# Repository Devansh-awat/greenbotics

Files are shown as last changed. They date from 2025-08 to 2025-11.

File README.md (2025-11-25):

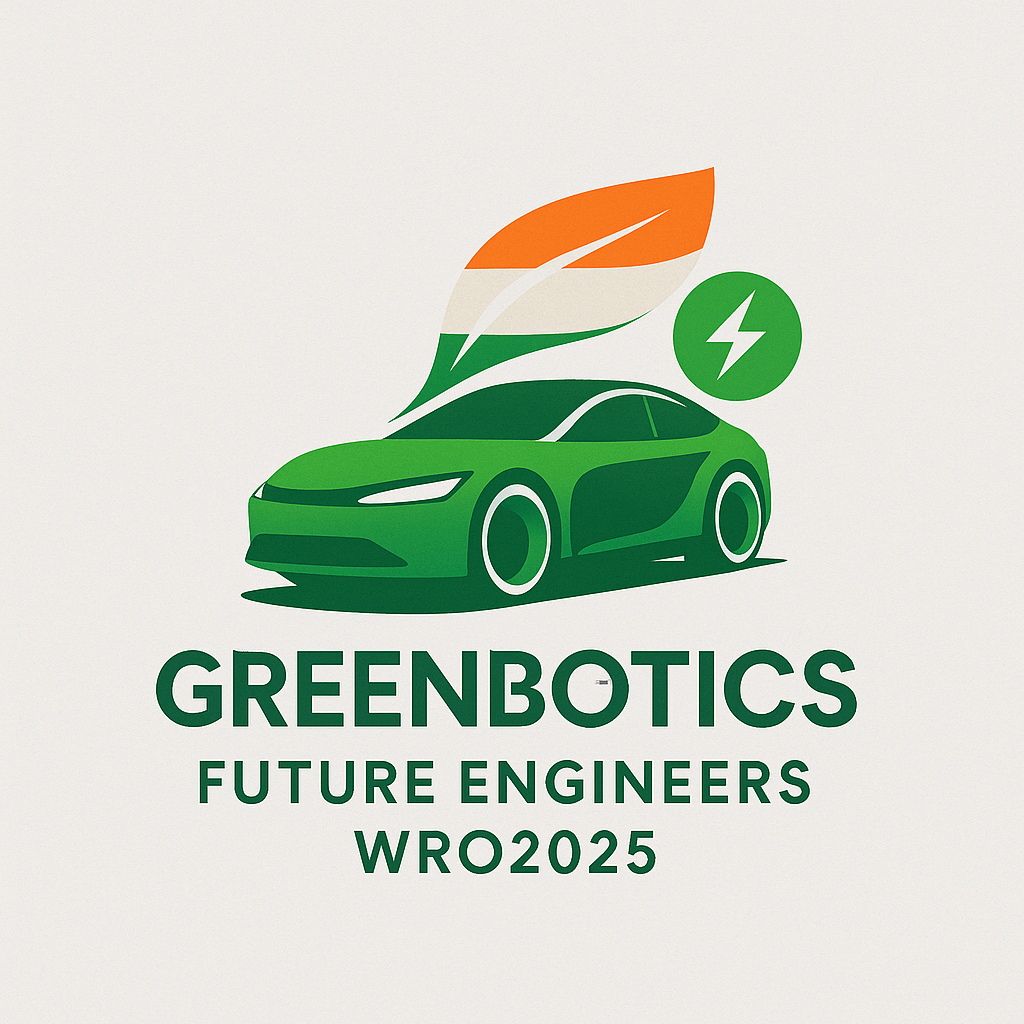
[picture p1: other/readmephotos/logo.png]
|  |
| :----------------------------------------------------------: |

| GithubQR | YoutubeQR |
| :--- | ---: |
| Scan QR to open Github repo | Scan QR to open YouTube video |

<div style="font-family: Baskerville; font-size: 28px; text-align: center; font-style: italic;">
    This Incredible Repository
</div>

Welcome to the Greenbotics 2025 repository! This repository contains everything we've worked on over the past ten months, including all our code and resources. You can also use this repository as a complete guide to understand and reconstruct the robot from the ground up.

## Table of Contents

- [The Team](#the-team)
- [The Challenge](#the-challenge)
  - [Our Vision](#our-vision)
  - [Skills We Learned](#skills-we-learned)
- [Photos of our Robot](#photos-of-our-robot)
- [Robot Performance Video](#robot-performance-video)
- [Mobility Management](#mobility-management)
  - [Powertrain](#powertrain)
  - [Steering System](#steering-system)
  - [Chassis](#chassis)
  - [Code for mobility components](#code-for-mobility-components)
- [Power and Sense Management](#power-and-sense-management)
  - [LiPo battery](#lipo-battery)
  - [Raspberry Pi](#raspberry-pi)
  - [Voltage Converter](#voltage-converter)
  - [Printed Circuit Board (PCB)](#printed-circuit-board-pcb)
  - [Camera](#camera)
  - [IMU](#imu)
  - [Distance Sensor](#distance-sensor)
  - [Multiplexer](#multiplexer)
  - [Code for sensors](#code-for-sensors)
- [Obstacle Management](#obstacle-management)
  - [Open Challenge Navigation Algorithm](#open-challenge-navigation-algorithm)
    - [Potential improvements in Open Navigation Algorithm](#potential-improvements-in-open-navigation-algorithm)
  - [Obstacle Challenge Navigation Algorithm](#obstacle-challenge-navigation-algorithm)
    - [Potential improvements in Obstacle Navigation Algorithm](#potential-improvements-in-obstacle-navigation-algorithm)
- [Engineering Factors](#engineering-factors)
  - [Design evolution](#design-evolution)
  - [From Nationals to Internationals!](#from-nationals-to-internationals)
- [Robot construction guide](#robot-construction-guide)
  - [1: Print the 3D parts](#1-print-the-3d-parts)
  - [2: Assemble the steering and drive train](#2-assemble-the-steering-and-drive-train)
  - [3: Attach the 3D mounts](#3-attach-the-3d-mounts)
  - [4: Fabricate the PCB](#4-fabricate-the-pcb)
  - [5: Soldering the electronics and gradual safe startup](#5-soldering-the-electronics-and-gradual-safe-startup)
  - [6: Download the code](#6-download-the-code)
  - [7: Robot stability](#7-robot-stability)
- [Major challenges faced](#major-challenges-faced)
- [How we used Github](#how-we-used-github)
- [Bill of Materials](#bill-of-materials)

# The Team

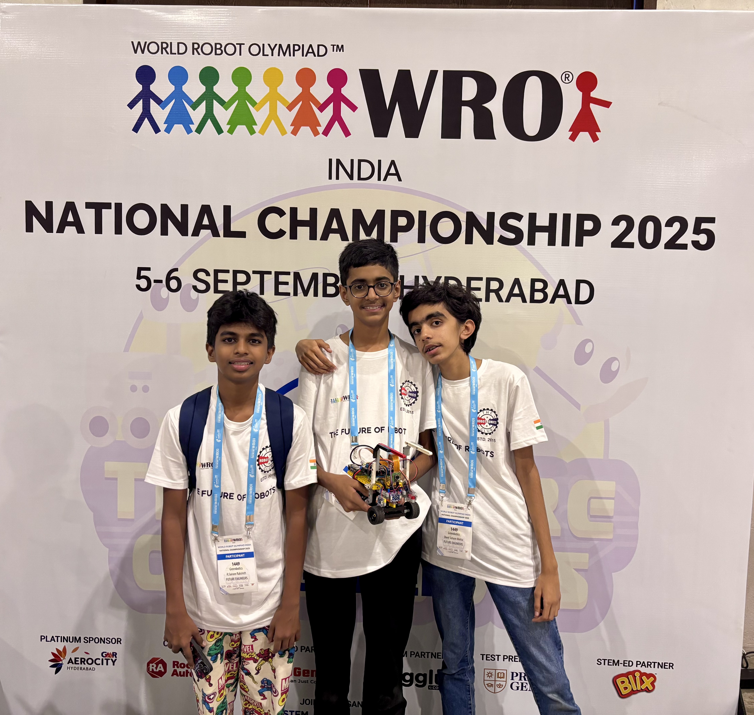
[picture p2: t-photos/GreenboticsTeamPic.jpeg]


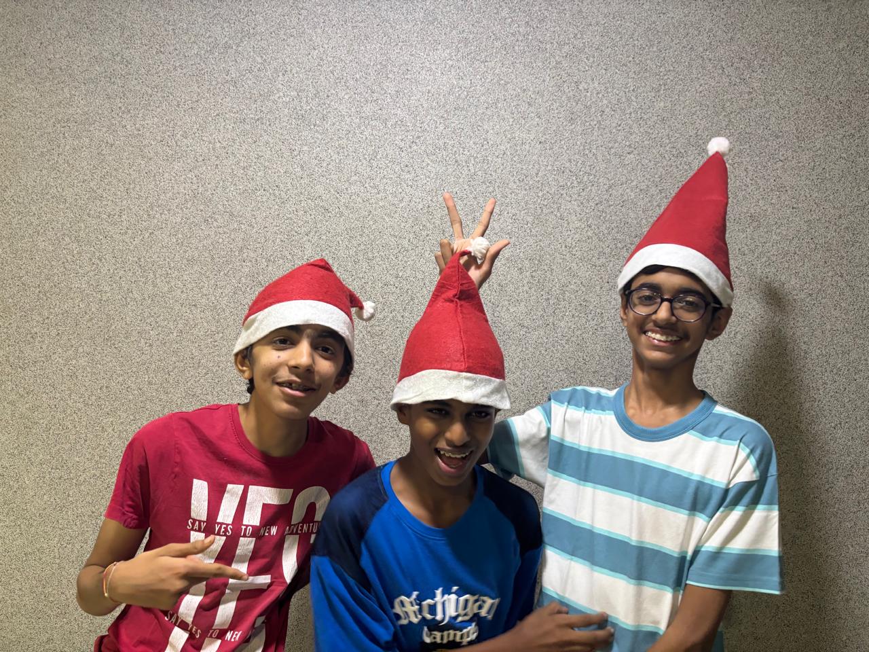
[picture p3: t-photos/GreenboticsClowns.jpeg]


<p style="text-align:center;">Yes. We did know the camera was on!</p>

---

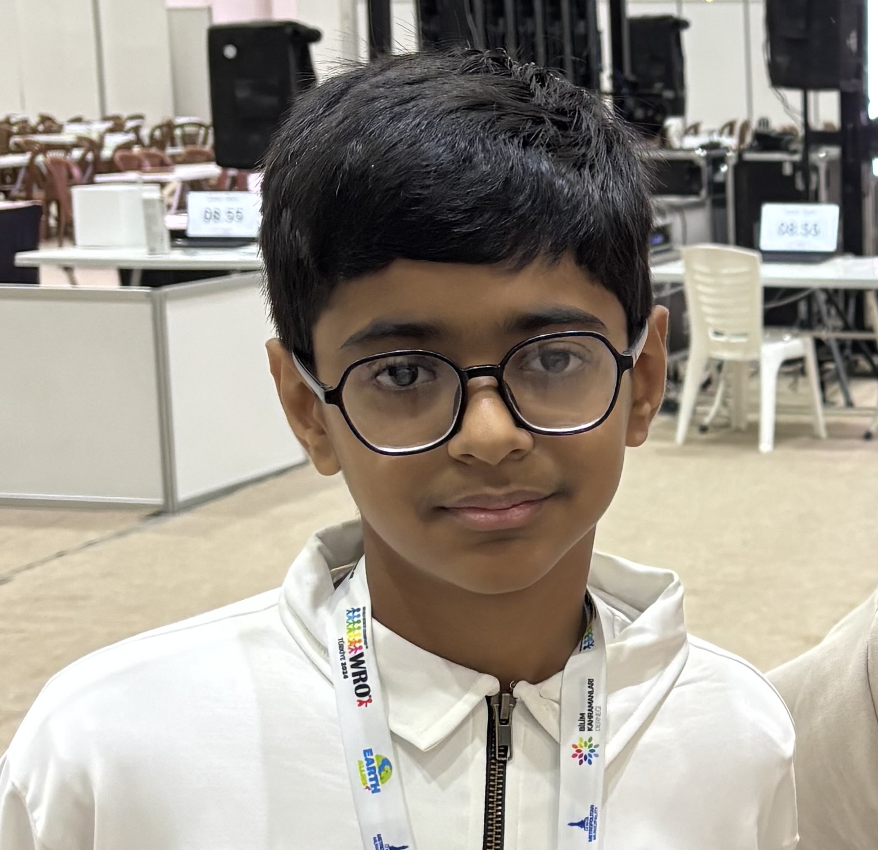
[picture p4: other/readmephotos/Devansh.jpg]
|  | Devansh<br/>Hi! I’m Devansh doing my second WRO season. Last year I represented India in the RoboMission category coming #25 in Internationals. This year I wanted a new challenge and learn new things. My hobbies are coding and robotics. |
| --- | --- |
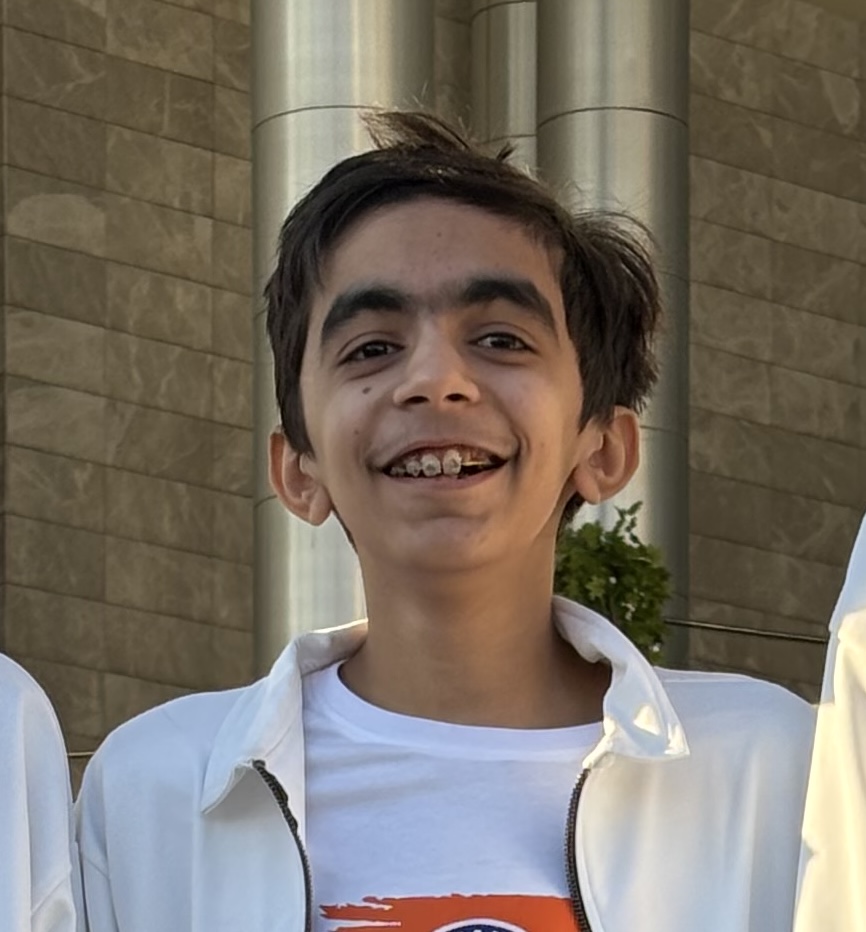
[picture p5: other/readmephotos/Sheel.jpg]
|  | **Sheel**<br/>**Hi! I'm Sheel. I'm 15, and doing my second WRO season. Last year, our team made it to the International Finals in Robomission Junior. Additionally, I'm learning competitive debate. I also have a dog, and both of us are obsessed with Monkeys.** |
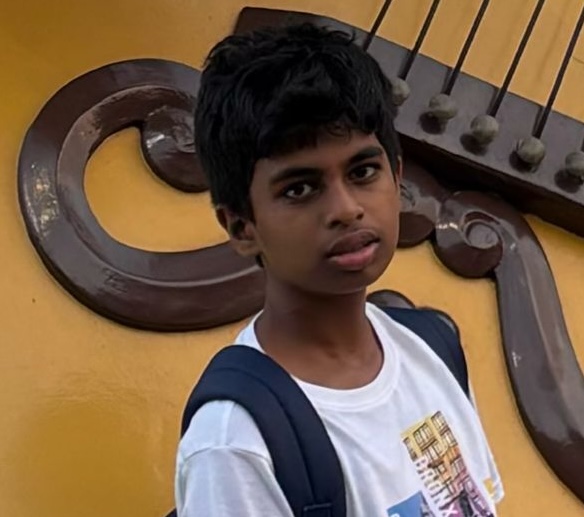
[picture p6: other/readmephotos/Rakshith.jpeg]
|  | **Rakshith**<br/>**I'm Rakshith, a 9th grader passionate about robotics and aspiring to study engineering in Germany. I love building drones, experimenting with sensors. I also have 3 dogs, and two of them live with my grandparents in Hyderabad.** |
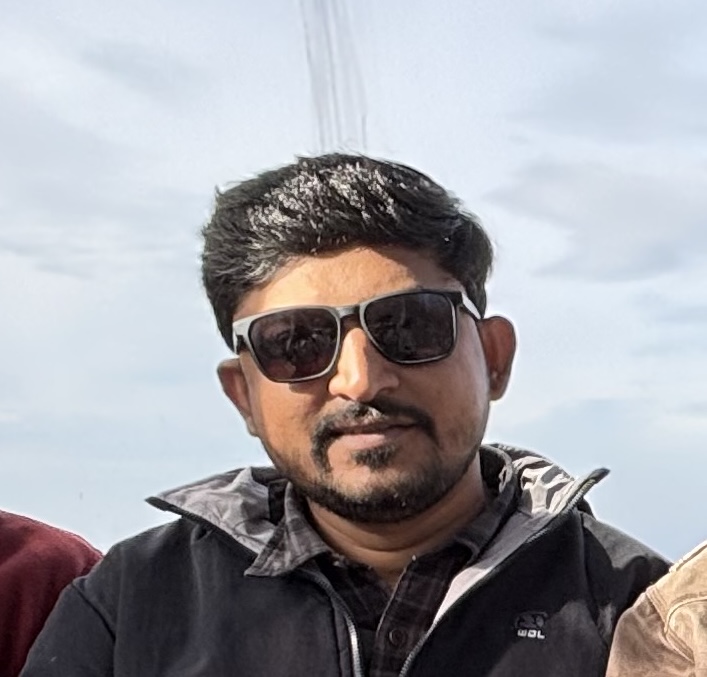
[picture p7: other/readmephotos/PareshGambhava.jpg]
|  | **Paresh Gambhava**<br/>**Mr. Paresh Gambhava is our chief coach from The Robotronics Club Ahmedabad. He is a robotics enthusiast, and electrical engineer by profession. He has vast experience training students for Robotics competition and projects.** |

# The Challenge

The [Future Engineer Challenge](https://wro-association.org/wp-content/uploads/WRO-2025-Future-Engineers-Self-Driving-Cars-General-Rules.pdf "View the season rulebook") for the 2025 WRO Season involves building an autonomous vehicle that can complete two challenges. The first challenge is the Open Challenge. This challenge involves the robot completing three full laps on the field. The field consists of outer boundary walls, and 4 inner walls that are randomly placed to form a closed rectangle.

The second challenge is the Obstacle Challenge. In the Obstacle Challenge red or green cuboids called Traffic Signs are placed along the course. The robot must complete three laps around the track while making sure to pass the red traffic signs from the left, and the green traffic signs from the right. The Obstacle Challenge also has a dedicated Parking Space. The robot must start and end in the parking space to attain full points. The walls placement is fixed for the Obstacle Challenge.

## Our Vision

With a deep interest in robotics and programming, the WRO Future engineers challenge was a great opportunity for us to work and build a robot together. We had been seeing other teams in our institute work on this problem last year, and it was greatly motivating for us to see them work. Having represented India in last years WRO RoboMission, we were excited to participate in new category and learn new things.

## Skills We Learned

**Technical Skills:**

- 3D printing and design
- PCB design and creation
- Raspberry Pi programming
- Computer vision and camera programming
- Hardware integration

**Soft Skills:**

- Teamwork
- Problem-solving
- Not go crazy when the robot doesn’t behave as expected !!!

# Photos of our Robot

We designed our robot with Raspberry Pi 5 as the main brain of the car. Raspberry Pi 5 had pre-integrations with the camera allowing us to use faster smarter image procesing algorithms which is critical in this robots design.
Having spent a lot of time working on LEGO-based hardware in the 2024 season, we chose to use many LEGO parts for our Robot's Hardware.  However the robot also uses a Raspberry Pi, Raspberry Pi camera, and other off the shelf electronic components.

| Top view | Bottom view |
| :---: | :---: |
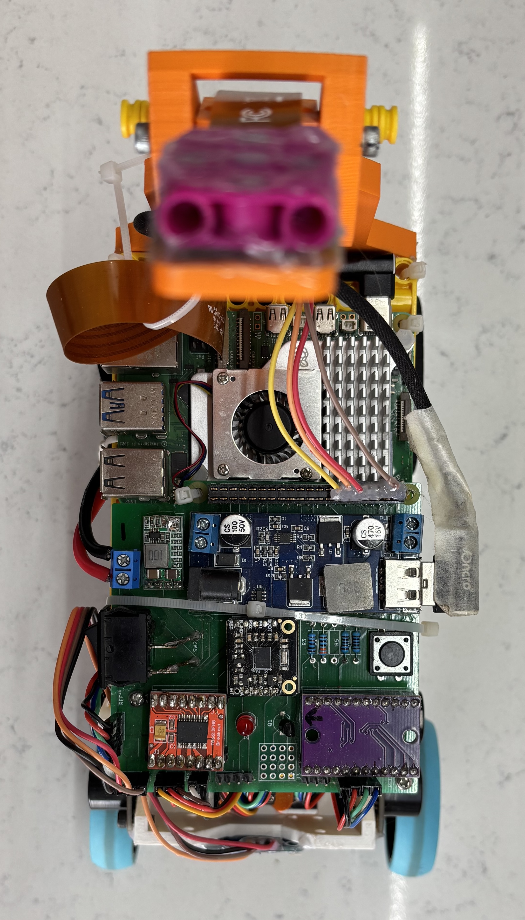
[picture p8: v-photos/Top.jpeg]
Top
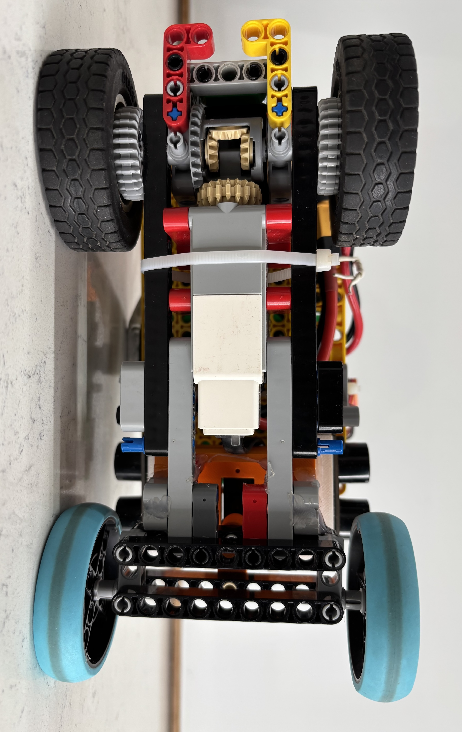
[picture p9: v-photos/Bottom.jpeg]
Bottom
|  |  |

| Front view | Rear view |
| :---: | :---: |
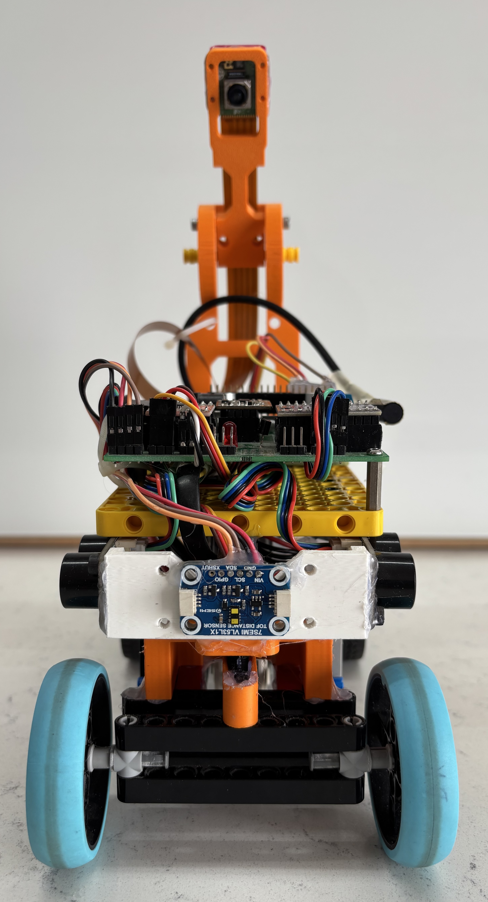
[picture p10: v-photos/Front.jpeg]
Front
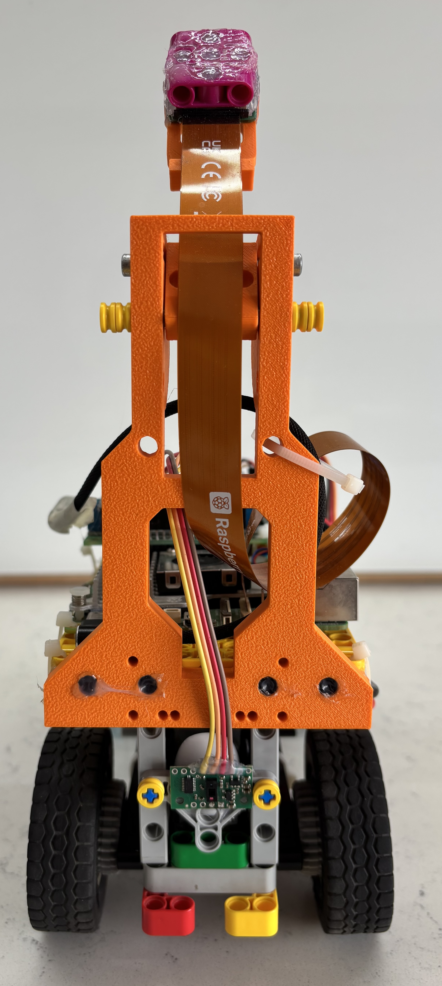
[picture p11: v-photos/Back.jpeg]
Back
|  |  |

| Left view | Right view |
| :---: | --- |
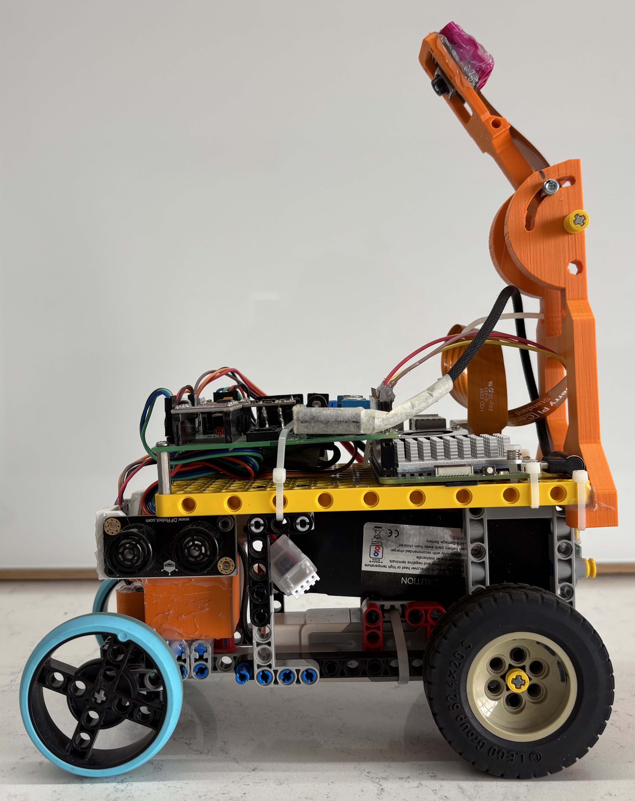
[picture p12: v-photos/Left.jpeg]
Left
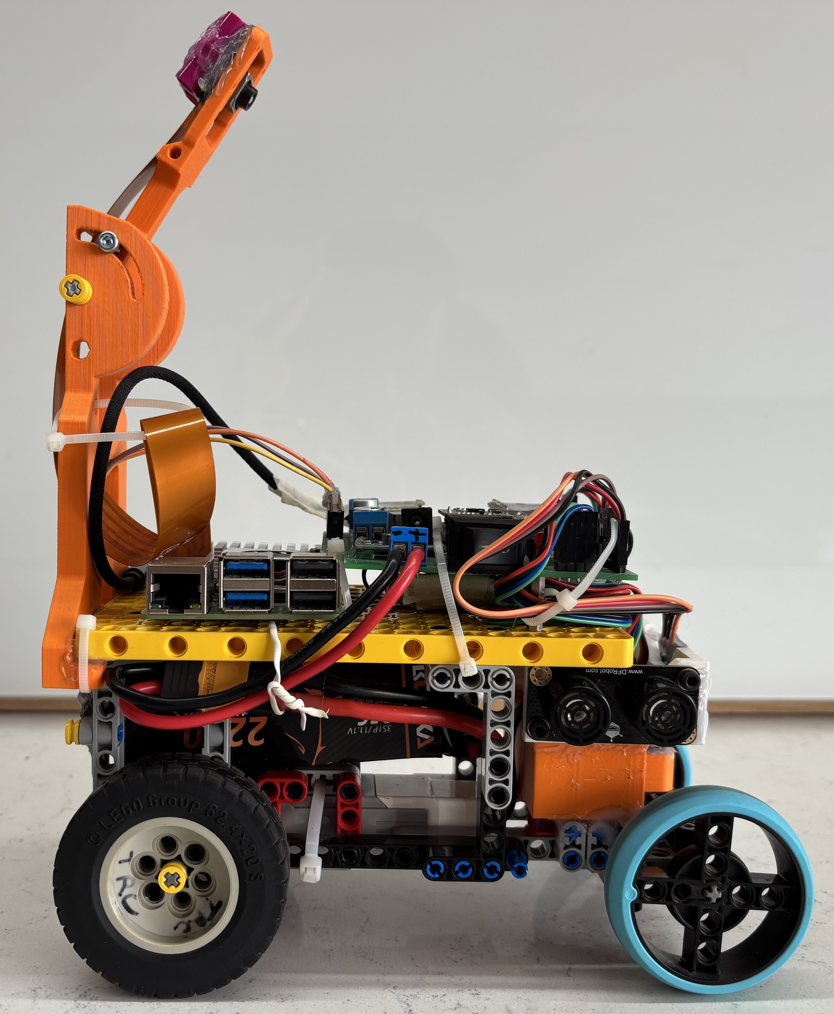
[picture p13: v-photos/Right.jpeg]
Right
|  |  |

# Robot Performance Video

This playlist consists of 3 videos that show our robot's construction, open challenge run as well as obstacle challenge run.

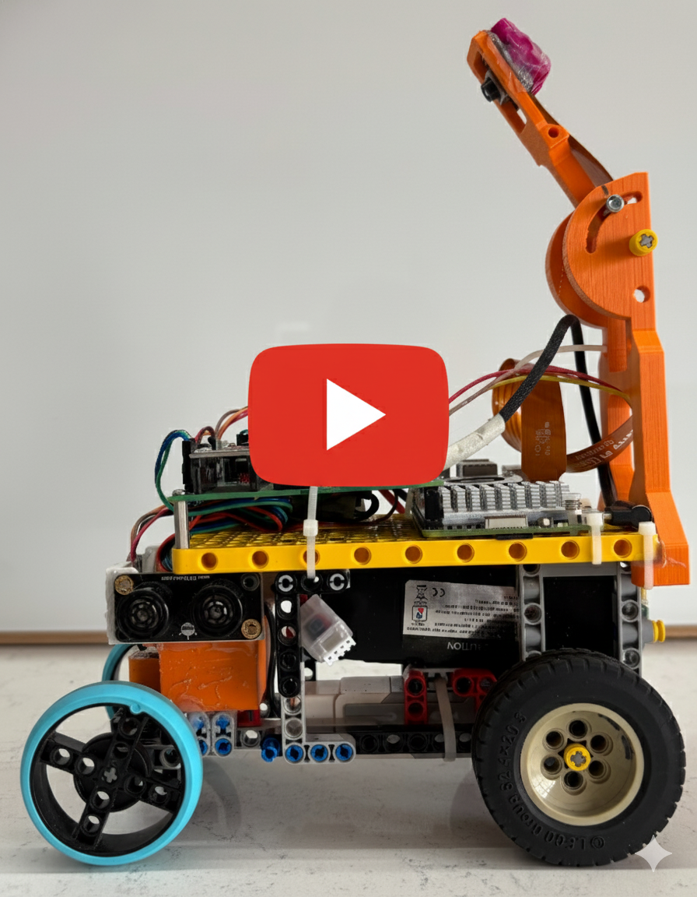
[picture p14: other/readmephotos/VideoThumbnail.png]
Robot Video
| [](https://www.youtube.com/playlist?list=PLtGeYglcz-LV6koN9wQThOjIqPL0-ONzv) | YoutubeQR <br />Scan QR code to open in YouTube |
| --- | --- |

---

# Mobility Management

Our robot's mobility system is designed around a LEGO-based chassis that balances ease of assembly with reliable performance. We selected a LEGO EV3 Medium Motor for propulsion due to its compatibility with our modular design approach, delivering 240-250 RPM at 9V through a differential drivetrain that enables smooth turning by allowing wheels to rotate at different speeds. For precise steering control, we integrated an SG90 servo motor with a custom 3D-printed mount that connects to our LEGO chassis. The TB6612FNG motor driver manages power delivery and speed control, while all components are securely mounted to our LEGO framework using standard connectors and custom PCB integration. This design prioritizes modularity and maintainability while providing the torque and precision needed for autonomous navigation challenges.

## Powertrain

### Motor

We chose to use a standard LEGO EV3 Medium Motor, as it easily integrates with the lego chassis and lego axle. This motor also embeds an encoder which could be used if required. However, the standard Lego connector doesn’t directly connect to our motor driver, therefore we identified the pinout of the LEGO motor and directly connected the wires to the motor driver. The pinout diagram of Lego EV3 motor is shown below

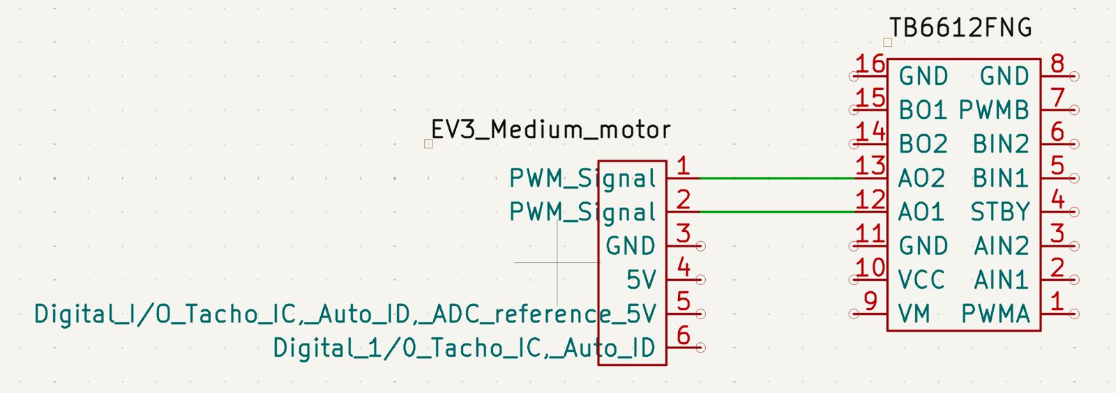
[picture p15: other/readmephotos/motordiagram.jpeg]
Motor Pinout Diagram


---
<table>
  <tr>
    <td width="50%" style="text-align: left;">
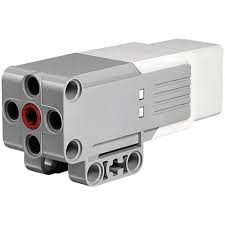
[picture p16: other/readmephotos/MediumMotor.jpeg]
EV3 Medium Motor
      
    </td>
    <td width="50%" style="text-align: left; vertical-align: top;">
      <h3>Specifications:</h3>
      <li>Name: LEGO EV3 Motor</li>
      <li>Voltage: 9V</li>
      <li>No Load Speed: 240 to 250 RPM</li>
      <li>Weight: 40g</li>
      <li>Encoder resolution: 1°</li>
    </td>
  </tr>
</table>

---

**Potential improvements:**

- Use the built-in encoder for more accurate movement and turns of the robot. Using the encoder allows for precise and accurate movements, helping in complex tasks like parking.

- Consider exploring more powerful non-Lego geared motors that are

    -Compact and lightweight

    -More powerful

    -Cheaper

### Drivetrain

Our EV3 motor is connected to a Lego axle that drives a gear connected to a Lego differential, which splits torque between two wheels. The differential lets both wheels rotate at different speeds when turning, thereby reducing the friction at each wheel, and making turns smoother. We used lego wheels as they are compatible with lego axle used for the chassis. We experimented with a wide variety of Lego wheels for the robot. Increasing the size of the rear wheel increased the robot speed almost linearly proportional to the wheel diameter. Increasing the width of the front tyres caused the robot to skid during turns, hence the front wheels are narrower to make smooth turns. The rear wheels are wider to provide sufficient friction to the vehicle.

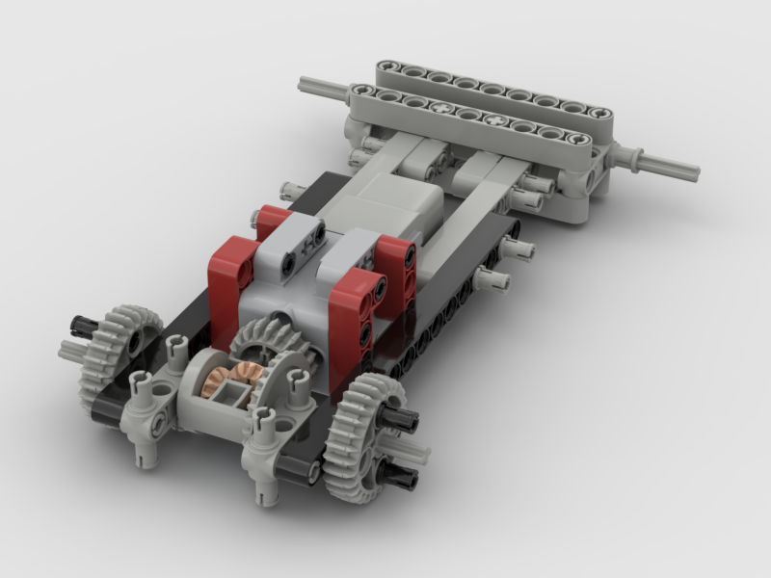
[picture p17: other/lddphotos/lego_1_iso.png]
lego_1_iso


**Potential Improvements**

- Explore alternative differential gear mechanisms to avoid the wheels slipping, especially on the smooth surface of the mat.
- Explore options for front wheels with vertical treads as the Lego narrow wheels do not have tread.

### Motor Driver

To control the current received by the motor and to control the speed of the drive motor, we utilized a SparkFun Dual TB6612FNG motor driver. The motor driver is connected to our PCB, and receives signals from the Raspberry Pi.

<table>
  <tr>
    <td width="50%" style="text-align: left;">
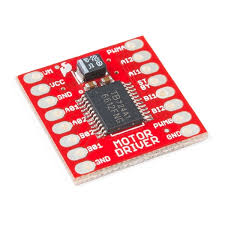
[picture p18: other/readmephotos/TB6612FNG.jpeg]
Motor Driver
      
    </td>
    <td width="50%" style="text-align: left; vertical-align: top;">
      <h3>Specifications:</h3>
      <li>Name: TB6612FNG</li>
      <li>Power Supply Voltage: 15V (Max)</li>
      <li>Average Output current: 1.2A</li>
      <li>Peak Output current: 3.2A</li>
      <li>Standby control to save power</li>
      <li>Built-in thermal shutdown circuit</li>
    </td>
  </tr>
</table>

**Potential Improvements:**

- Explore motor driver that can output higher currents, if we upgrade existing motors to higher performance motors

## Steering System

For our steering mechanism, we needed a design that was precise. Like all other aspects of our robot’s design, our first choice was to use a Lego based mechanism. Ackerman steering is a popular choice in automobiles, as the front inner wheel turns more than the front outer wheel, thereby reducing skid. However it was complicated to build it. We first tried the simpler parallel steering mechanism and it turned out to be pretty good for our robot, so we didn't consider Ackerman steering.

The steering could have been driven by any encoder based motor (such as a spike prime small motor) as a makeshift servo motor. The problem was, that while any Lego motor would have been both highly precise and easy to integrate, even the smallest motor was too bulky and required integration with motor driver.

Therefore, we decided to use an off the shelf servo motor, which was not only small but can be driven directly by Raspberry Pi's output port. To integrate it with our Lego based design, we 3D printed a custom servo mount which could be attached with Lego screws to the front of the chassis directly behind the front wheel, while simultaneously hot gluing the servo horn to 3D printed component that couples the horn to the axle of the front wheels.

**Potential Improvements:**

- Explore if Ackerman steering provides better maneuverability.

### Servo Motor

Our steering system is centered around the SG90 servo motor, which provides precise angular control, making it highly suitable for steering applications where accuracy is essential. Unlike standard DC motors, the SG90 has a built-in feedback mechanism that allows it to hold a commanded angle reliably without additional sensors. Despite its compact size, it delivers sufficient torque to handle the demands of turning the steering mechanism, ensuring stability.

<table>
  <tr>
    <td width="50%" style="text-align: left;">
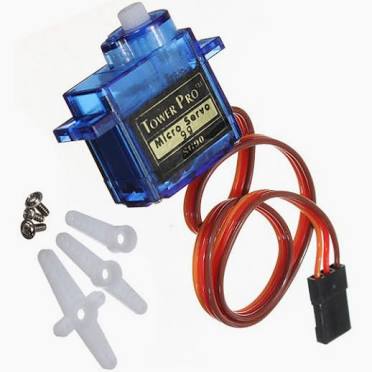
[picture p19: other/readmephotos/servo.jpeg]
Servo Motor
      
    </td>
    <td width="50%" style="text-align: left; vertical-align: top;">
      <h3>Specifications:</h3>
      <li>Name: SG90</li>
      <li>Operating voltage: 3.0V - 7.2V</li>
      <li>Weight: 9g</li>
    </td>
  </tr>
</table>

<table>
  <tr>
    <td width="50%" style="text-align: left;">
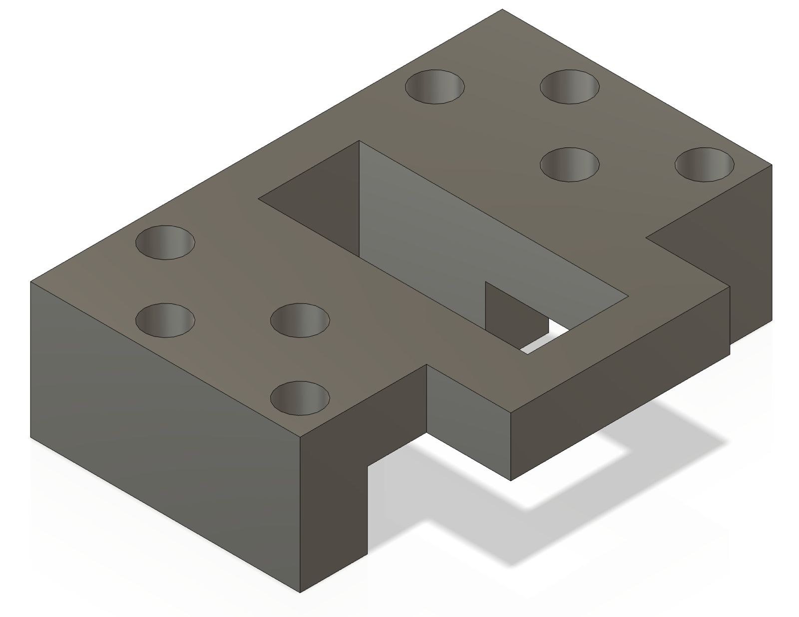
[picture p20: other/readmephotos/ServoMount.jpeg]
Servo Motor
      
    </td>
    <td width="50%" style="text-align: left; vertical-align: top;">
      <h3>Servo mount</h3>
      <li>To connect the servo motor to our robot, we designed and 3D printed a custom Servo Mount</li>
      <li>A diagram of our servo mount is shown to the left.</li>
      <li>A 3D Printable file is provided in the models folder.</li>
    </td>
  </tr>
</table>

**Challenges:**

For a brief period, we used an MG90 servo motor instead of our current SG90 motor. An MG90 has metal gears instead of plastic gears, which we believed would make it more reliable. However, the MG90 gears broke in one of our test runs, and we reverted back to the SG90

**Potential Improvements:**

- 3D print the servo horn to directly connect to the chassis without gluing

## Chassis

When starting this project, we realized that the bulk of our effort would go into building autonomous driving software. As we wanted to spend more time on software, and had already spent a considerable amount of time using Lego hardware for our 2024 Robomission challenge, we **custom designed** the base chassis from elementary Lego parts and rest of the chassis with **3D printed parts**.

This approach has many benefits, the primary one being ease of integration. Lego parts can easily be snapped on and off, making chassis development far easier and less time consuming. Making changes to a non-Lego chassis would have meant that each time we wanted to make a change to our chassis, we would have to make new 3D prints, increasing time, cost, waste and materials used.

All sensors like the camera, ultrasonic sensors and TOF sensors are attached to the base chassis with 3D printed mounts. This provides robust attachment of the the sensors to the main body. The prototype was built with hot gluing these sensors to the body but this wasn't robust and would come off.

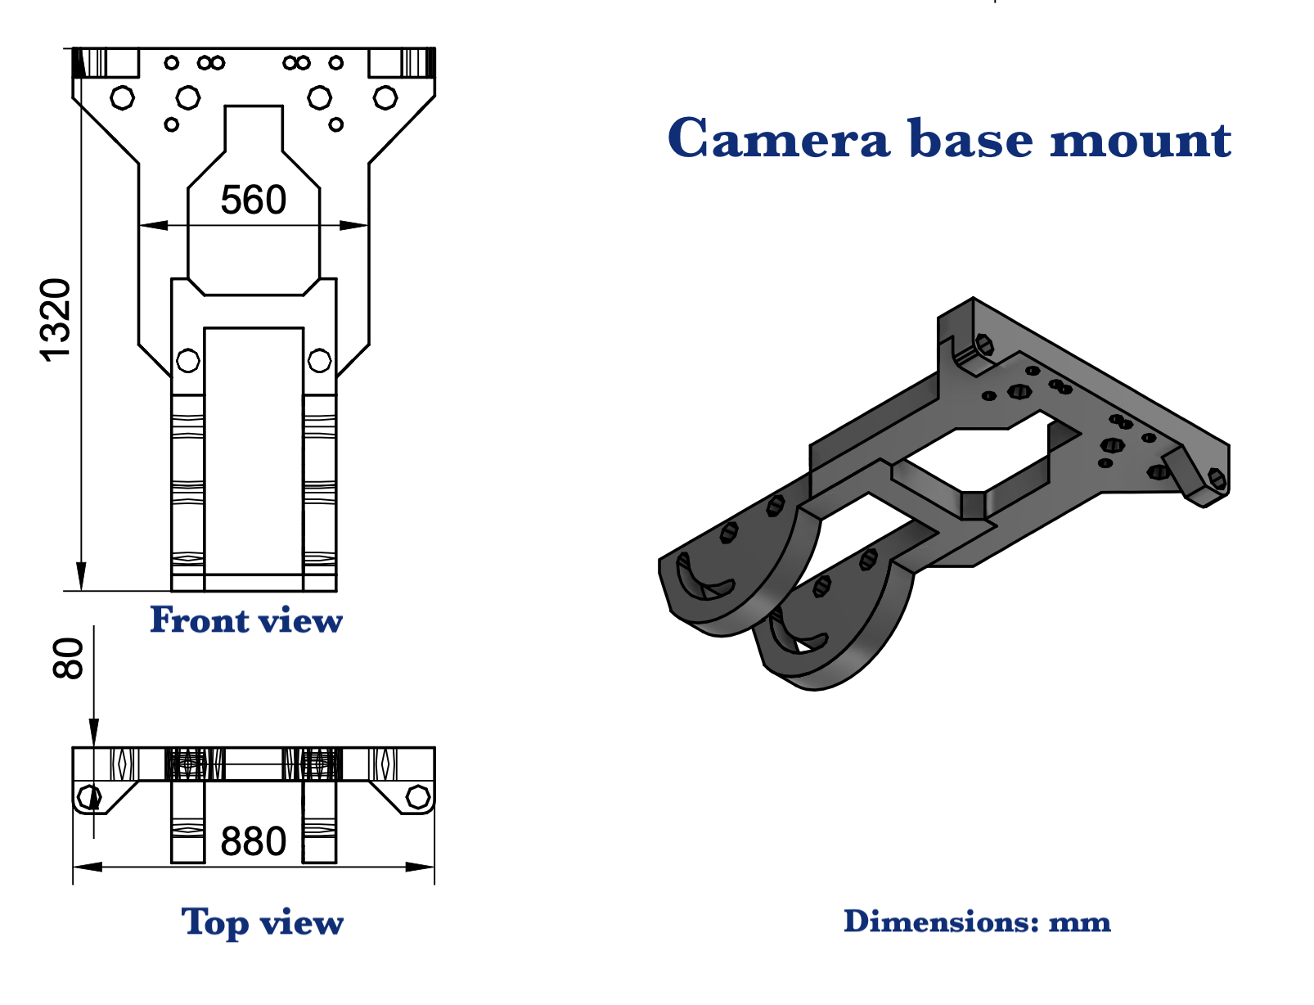
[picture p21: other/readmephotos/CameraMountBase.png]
CameraMountBase
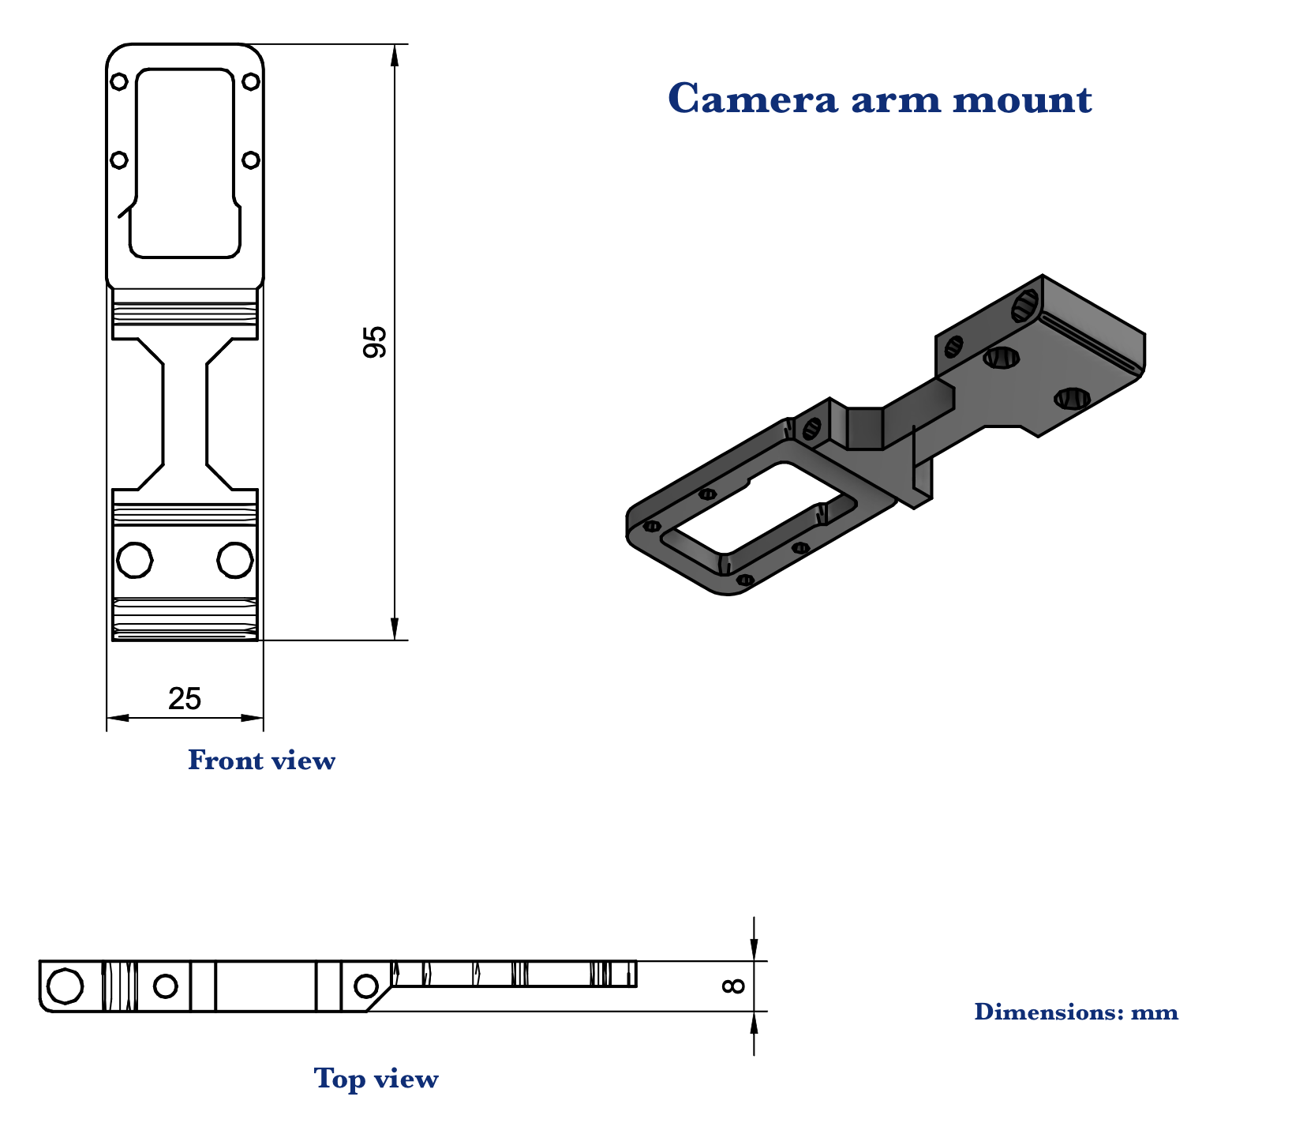
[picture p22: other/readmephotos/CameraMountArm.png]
|  |  |
| --- | --- |
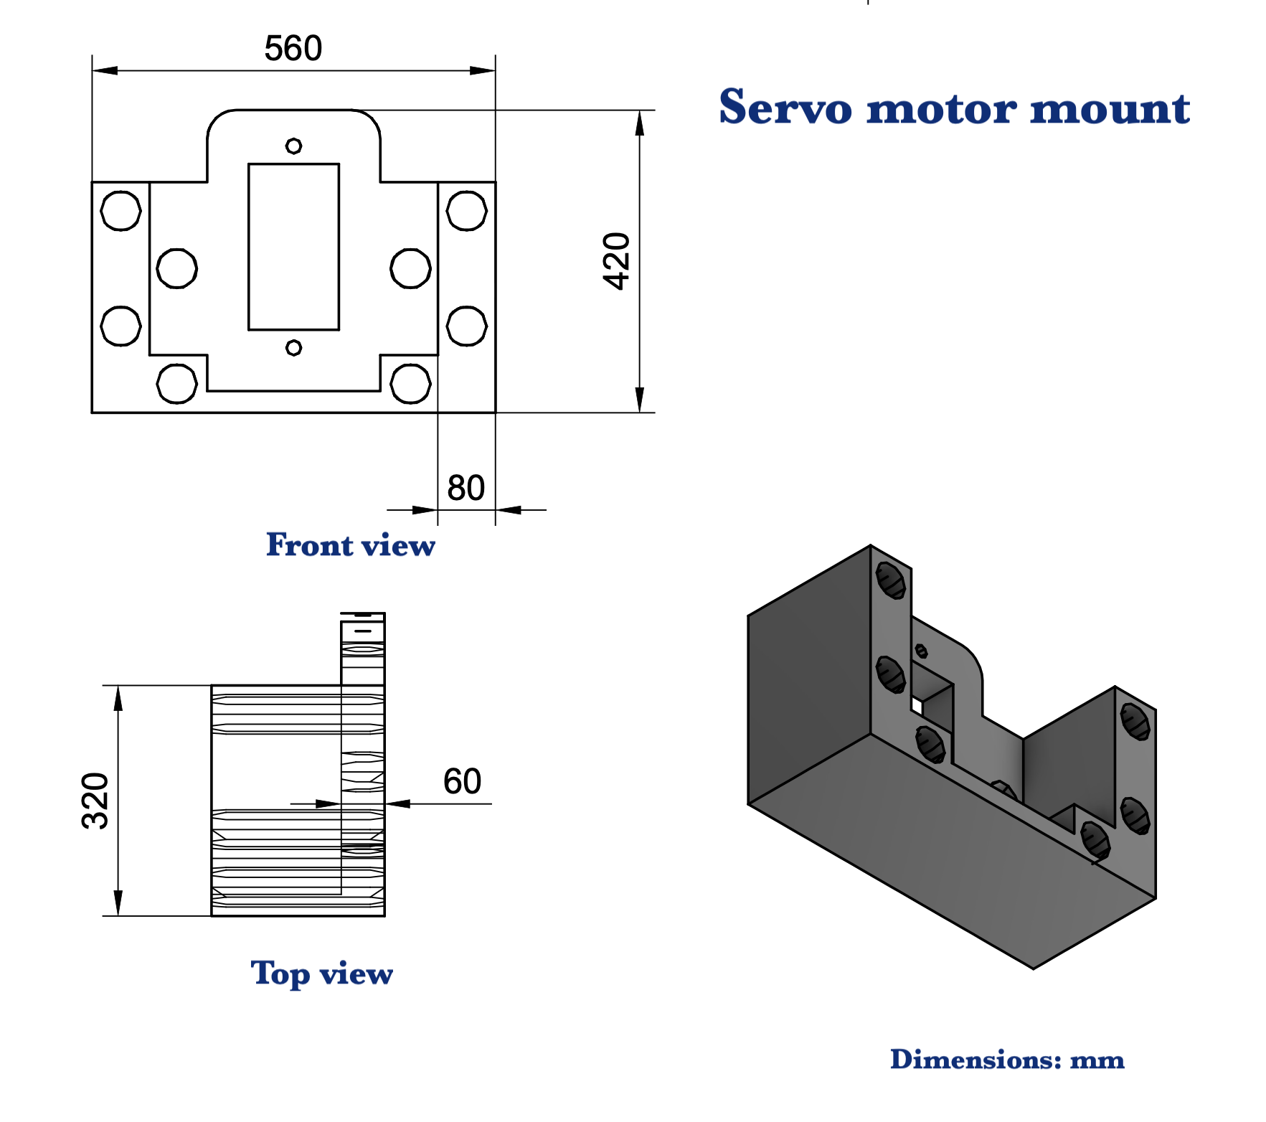
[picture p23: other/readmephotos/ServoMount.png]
ServoMount
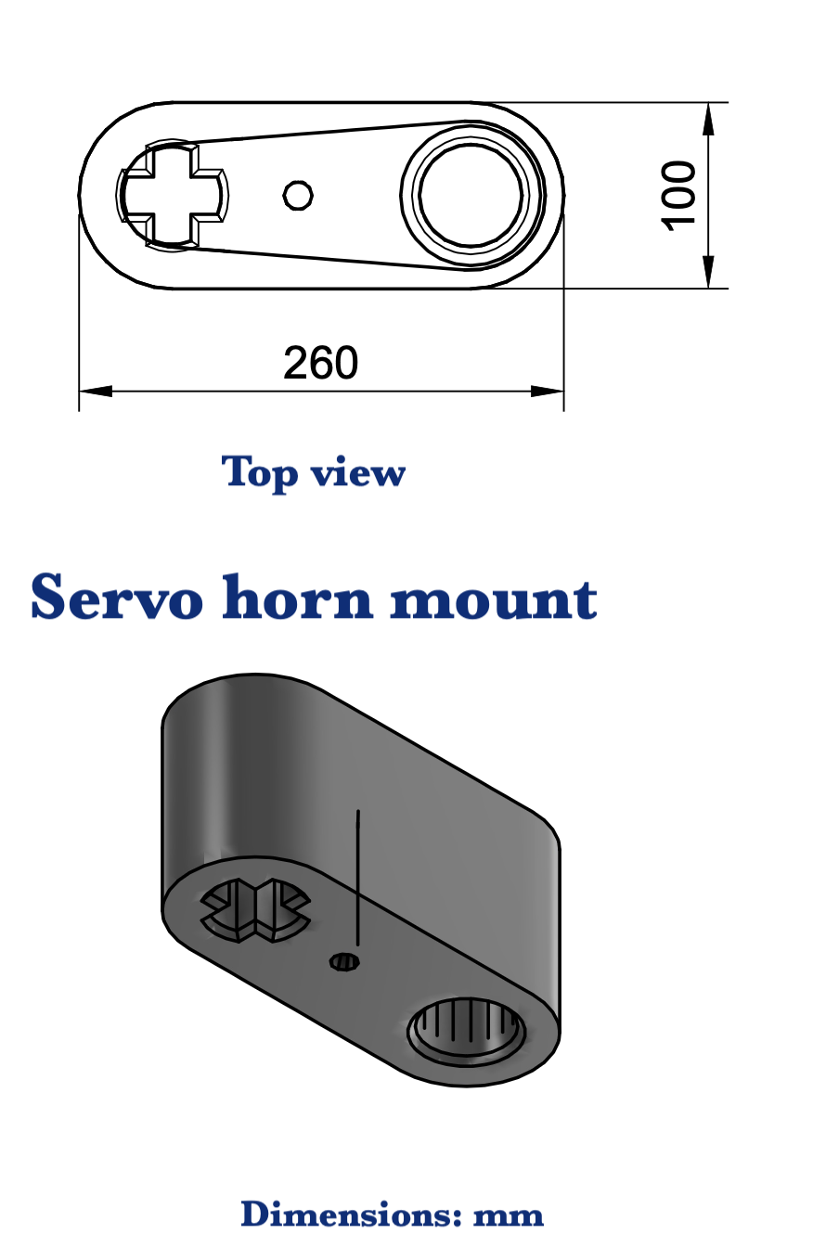
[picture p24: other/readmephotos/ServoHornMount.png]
ServoHornMount
|  |  |

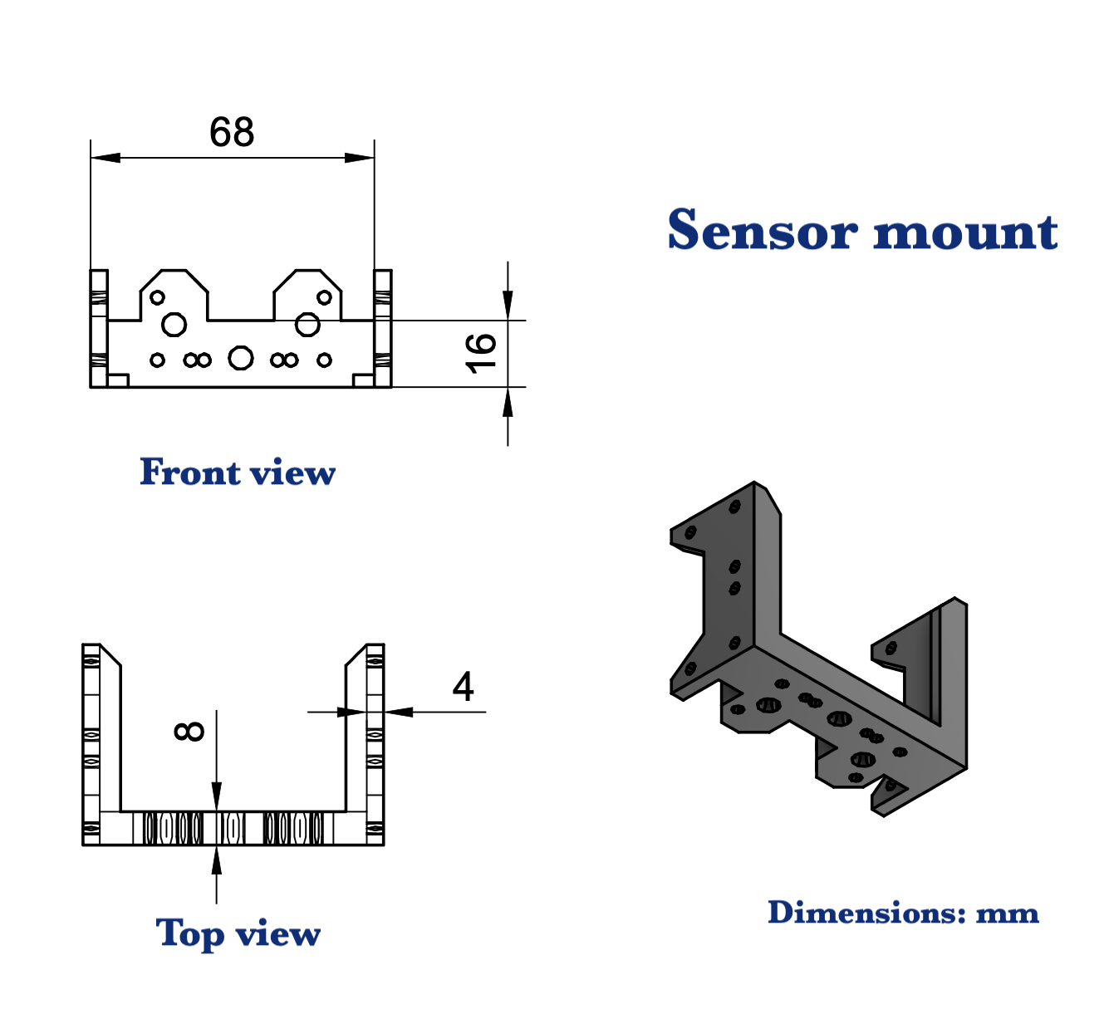
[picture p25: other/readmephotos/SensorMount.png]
SensorMount
|  |
| :----------------------------------------------------------: |

**Potential Improvements:**

- Despite being mounted on a thick 3D-printed mount, the camera vibrates when the robot is in motion, blurring the image. The mount could be coupled with vibration damping material.
- Lightweight suspension can be added to the chassis to enhance stability.
- The Raspberry Pi's cooling fan can be covered with a custom 3D printed cover to avoid dust and debris getting into the fan.
- The current 3D printed parts are printed with 100% infill for robustness but it increases the weight. We could explore an optimum infill that gives the minimum strength at the lowest possible weight.

## Code for mobility components

### Motor Control

Controls the drive motor speed and direction using PWM (pulse-width modulation) signals sent to the TB6612FNG motor driver.

#### Initialization

```python
def initialize():
    """Initializes the DC motor driver and PWM."""
    global gpio_handle, motor_pwm
    try:
        gpio_handle = lgpio.gpiochip_open(0)
        lgpio.gpio_claim_output(gpio_handle, config.AIN1_PIN)
        lgpio.gpio_claim_output(gpio_handle, config.AIN2_PIN)
        lgpio.gpio_claim_output(gpio_handle, config.STBY_PIN)
        
        motor_pwm = HardwarePWM(
            pwm_channel=config.MOTOR_PWM_CHANNEL,
            hz=config.MOTOR_PWM_FREQ,
            chip=config.MOTOR_PWM_CHIP,
        )
        motor_pwm.start(0)
        print("INFO: Motor Initialized.")
        return True
    except Exception as err:
        print(f"FATAL: Motor failed to initialize: {err}")
        return False
```

**Explanation:** We set up the GPIO pins that control the motor direction (AIN1, AIN2) and standby mode (STBY). We also initialize the PWM signal that controls motor speed.

#### Motor Control Functions

```python
def forward(speed):
    """Drives the motor forward at a given speed."""
    if gpio_handle:
        lgpio.gpio_write(gpio_handle, config.STBY_PIN, 1)  # Enable motor
        lgpio.gpio_write(gpio_handle, config.AIN1_PIN, 1)  # Forward direction
        lgpio.gpio_write(gpio_handle, config.AIN2_PIN, 0)
        _set_speed(speed)  # Set speed 0-100

def reverse(speed):
    """Drives the motor in reverse at a given speed."""
    if gpio_handle:
        lgpio.gpio_write(gpio_handle, config.STBY_PIN, 1)  # Enable motor
        lgpio.gpio_write(gpio_handle, config.AIN1_PIN, 0)  # Reverse direction
        lgpio.gpio_write(gpio_handle, config.AIN2_PIN, 1)
        _set_speed(speed)

def brake():
    """Brakes the motor by shorting its terminals."""
    if gpio_handle:
        lgpio.gpio_write(gpio_handle, config.STBY_PIN, 1)
        lgpio.gpio_write(gpio_handle, config.AIN1_PIN, 1)  # Both pins high = brake
        lgpio.gpio_write(gpio_handle, config.AIN2_PIN, 1)
        _set_speed(0)
```

**Explanation:** These functions control motor direction by setting the AIN1 and AIN2 pins. Forward sets AIN1=1 and AIN2=0. Reverse does the opposite. Brake sets both to 1, which stops the motor quickly.

---

### Servo Steering

Controls the steering servo angle using PWM signals. The servo position determines the steering direction.

#### Initialization

```python
def initialize():
    """Initializes the servo motor PWM."""
    global servo_pwm
    
    for attempt in range(1, 6):  # Try up to 5 times
        try:
            servo_pwm = HardwarePWM(
                pwm_channel=config.SERVO_PWM_CHANNEL,
                hz=config.SERVO_PWM_FREQ,
                chip=config.SERVO_PWM_CHIP,
            )
            servo_pwm.start(0)
            set_angle(0.0)  # Center the servo
            time.sleep(0.5)
            print("INFO: Servo Initialized.")
            return True
        except PermissionError as err:
            print(f"WARNING: Servo PWM permission denied (attempt {attempt}/5): {err}")
            time.sleep(0.1 * attempt)
    
    print("FATAL: Servo failed to initialize after 5 attempts")
    return False
```

**Explanation:** We initialize the PWM signal for the servo. The servo needs a specific frequency (50 Hz) and pulse width to set its angle. We center it at 0 degrees during startup.

#### Servo Angle Control

```python
def set_angle(input_angle: float):
    """Sets the servo to a specific angle (-45 to +45 degrees)."""
    if servo_pwm is None:
        return
    
    # Clamp angle to safe limits
    clamped_angle = max(-45, min(45, input_angle))
    
    # Convert angle to PWM duty cycle
    # Servo expects 1-2ms pulse width at 50Hz frequency
    pulse_width_ms = 1.5 + (clamped_angle / 90) * 0.5
    duty_cycle = (pulse_width_ms / 20) * 100
    
    servo_pwm.change_duty_cycle(duty_cycle)
```

**Explanation:** Servo motors work by receiving a PWM signal with a specific pulse width. A 1.5ms pulse = center (0°), 1ms = full left (-90°), 2ms = full right (+90°). We calculate the duty cycle based on the desired angle.

# Power and Sense Management

Our robot uses a Raspberry Pi 5 to process data from several sensors. We use ultrasonic and TOF sensors for distance, an IMU for orientation, and a camera for autonomous driving. A Li-Po battery powers the entire system.

## LiPo battery

Our robot uses a Bonka 11.1V 2200mAh LiPo battery, commonly found in drones and quadcopters. We chose this battery because its compact form factor fits in the narrow space beneath the chassis. Mounting the heavy battery low in the robot lowers the center of mass, which improves stability.

<table>
  <tr>
    <td width="50%" style="text-align: left;">
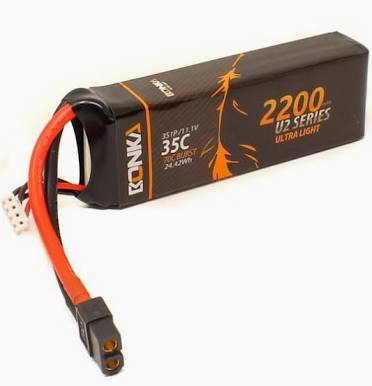
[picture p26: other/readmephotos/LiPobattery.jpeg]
LiPo Battery
      
    </td>
    <td width="50%" style="text-align: left; vertical-align: top;">
      <h3>Specifications:</h3>
      <li>Maximum Voltage: 12.6V </li>
      <li>Nominal Voltage: 11.1V </li>
      <li>Capacity: 2200mAh</li>
      <li>Discharge Current: 35C</li>
      <li>Weight: 175g</li>
    </td>
  </tr>
</table>

---
**Potential Improvements**

- Implement a battery level indicator
- Explore if a Lithium-Ion battery is available in the required form factor, as it

    - Is safer

    - Has more charge cycles

    - Doesn't require a complex charger that a LiPo requires
    
    - Can be easily removed and replaced with another charged battery
---
## Raspberry Pi

The heart of our robot is the Raspberry Pi 5 microcomputer. It processes inputs from our distance sensors, runs image processing algorithms on the live camera feed and controls the motors to drive the robot to achieve its desired goals.

We chose this particular model as it seamlessly integrates with a camera, making it easier to use than similar computers or microcontrollers such as an Arduino or ESP32. Additionally, we also wanted to take advantage of the Raspberry Pi 5 being far more powerful than other processors, allowing us to use newer and improved image processing technologies that deliver more accurate results but may require greater computing power.

**Potential Improvements**

- Use Arduinos and compatible cameras to make this robot much cheaper to design

<table>
  <tr>
    <td width="50%" style="text-align: left;">
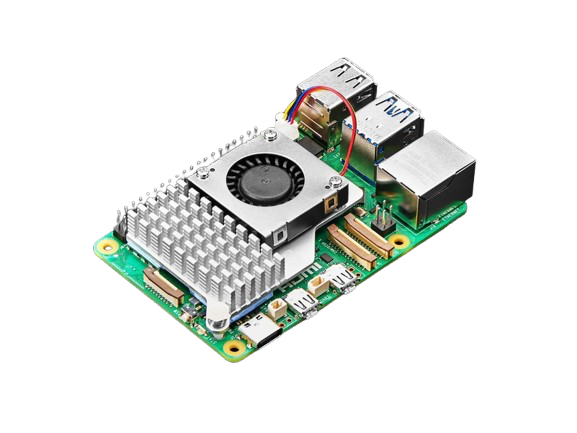
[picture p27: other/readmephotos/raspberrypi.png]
Raspberry Pi 5
      
    </td>
    <td width="50%" style="text-align: left; vertical-align: top;">
      <h3>Specifications:</h3>
      <li>Name: Raspberry Pi 5 </li>
      <li>RAM: 8GB</li>
      <li>Pins: 40</li>
      <li>Input Voltage: 5V</li>
    </td>
  </tr>
</table>

## Voltage Converter

Our battery provides 12V, but our Raspberry Pi requires 5V and our motor requires 9V. To supply these lower voltages safely, we used a XY-3606 step-down (buck) voltage converter.

**Potential Improvements**

- Use a linear converter to reduce costs
- Use a buck converter that is more efficient and provides more power at different voltages. This ensures that all components running at all voltages can be used

<table>
  <tr>
    <td width="50%" style="text-align: left;">
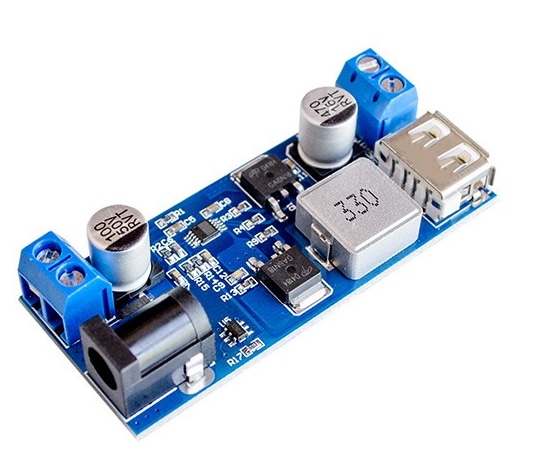
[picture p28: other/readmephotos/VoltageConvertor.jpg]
Voltage Converter
      
    </td>
    <td width="50%" style="text-align: left; vertical-align: top;">
      <h3>Specifications:</h3>
      <li>Name: XY-3606 </li>
      <li>Working voltage: DC 9V–36V</li>
      <li>Output voltage: 5.2V</li>
    </td>
  </tr>
</table>

## Printed Circuit Board (PCB)

In our first draft of the robot, there were many criss-crossing wires between many different components. A lack of clean arrangement for the wires made the robot very messy to handle. During practice runs, wires would routinely get loose, making it difficult to troubleshoot errors.

To solve this, we designed a PCB which cleanly connected all of our components together, making the robot far cleaner and reliable.

Here is a comparison showing our robot before and after the PCB

| Before | After |
| --- | --- |
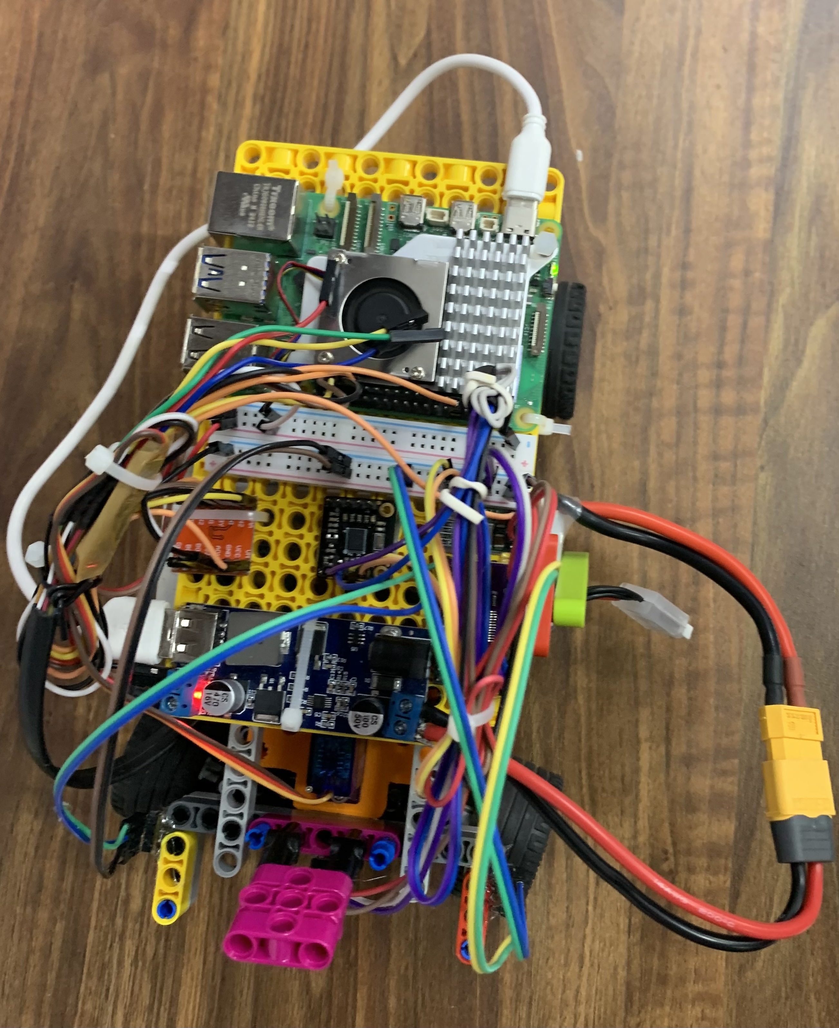
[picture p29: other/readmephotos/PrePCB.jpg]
Robot Before PCB
|  | Robot After PCB |

<table>
  <tr>
    <td width="50%" style="text-align: left;">
      <img src="./other/readmephotos/PCB.jpeg"" alt="Voltage Converter" width="70%">
    </td>
    <td width="50%" style="text-align: left; vertical-align: top;">
      <h3>PCB</h3>
      <li>This is our PCB image with all components mounted</li>
      <li>The 'models/PCB' folder contains the files required to print this PCB</li>
    </td>
  </tr>
</table>

## Camera

For image detection, we are using the Raspberry Pi Camera Module 3. This uses a CMOS sensor, the Sony IMX708. Apart from its ease of integration with the Raspberry Pi, the Camera module 3 has autofocus, wide-angle and low-light performance, all of which are very useful in a competition setting.

We explored few other alternatives as well. The Raspberry Pi AI camera provides built in detection for many objects, but has a limited Field Of View which didn't work for our requirements. The Raspberry Pi HQ camera though bulky comes with a standard CS mount that allowed us to mount different fish eye lenses. A fish eye lens camera provides a much larger Field Of View (160° - 180°) even when mounted in the front on a straight mount at 10cm height. This allows us to cut off the field view above the black walls making the robot resilient to off field objects. However the image is distorted towards the edges and tuning the robot to detect objects proved difficult for us.

<table>
  <tr>
    <td width="50%" style="text-align: left;">
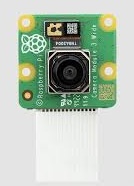
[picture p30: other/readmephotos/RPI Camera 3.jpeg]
RPI Camera
      
    </td>
    <td width="50%" style="text-align: left; vertical-align: top;">
      <h3>Specifications:</h3>
      <li>Name: Camera Module 3 </li>
      <li>Resolution: 11.9 megapixels</li>
      <li>Horizontal/vertical: 4608 × 2592 pixels</li>
      <li>Autofocus, Wide-angle and Low-light performance</li>
    </td>
  </tr>
</table>

**Potential Improvements**

- Use an alternative wide angle AI camera to process data on the camera itself. This will reduce processing load on the Raspberry Pi.
- Attempt to resolve tuning issues with fish eye camera to ignore off field objects.

## IMU

Our robot uses the BNO055 IMU (Inertial Measurement Unit) to help it maintain direction when moving straight, and to make turns more accurate. The BNO055 combines data from an accelerometer, gyroscope, and magnetometer to provide absolute orientation, which reduces drift and allows the robot to correct its heading in real time.

<table>
  <tr>
    <td width="50%" style="text-align: left;">
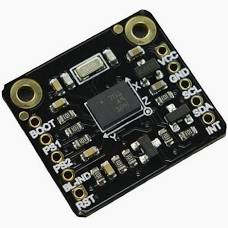
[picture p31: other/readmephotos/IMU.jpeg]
IMU
      
    </td>
    <td width="50%" style="text-align: left; vertical-align: top;">
      <h3>Specifications:</h3>
      <li>I2C Address: 0x28 </li>
      <li>Gyroscope: Range ±125°/s to ±2000°/s</li>
      <li>Accelerometer: Range ±2g, ±4g, ±8g, ±16g</li>
    </td>
  </tr>
</table>

**Potential Improvements**

- Move the IMU away from areas of magnetic interference
- Use higher quality IMUs such as the BNO085

## Distance Sensor

Apart from the camera, our robot uses TOF based distance sensors VL53L1X / VL53L8CX and URM09 Ultrasonic sensor to gather inputs. The sensors are mounted on the front, back, left, and right of the robot respectively. The front and back sensors are used to avoid hitting the parking walls. The left and right sensors are used to detect the starting direction for obstacle challenge. They could potentially be used for a surprise rule that may be announced at the competition.

**Reasons for using different sensors**

- Ultrasonic sensors are not affected by strong lighting at competition arenas and are useful to detect objects at larger distance. This is useful for wall detection.
- Some TOF sensors could potentially be affected by strong lighting at competition arenas, but are usually safe over short distances. This is useful for parking.
  - The back sensor is attached to the edge of the rear chassis hence requires min 2cm range.
  - The front sensor is attached to the inner cavity behind the front wheels hence can work with 4cm range.

<table>
  <tr>
    <td width="50%" style="text-align: left;">
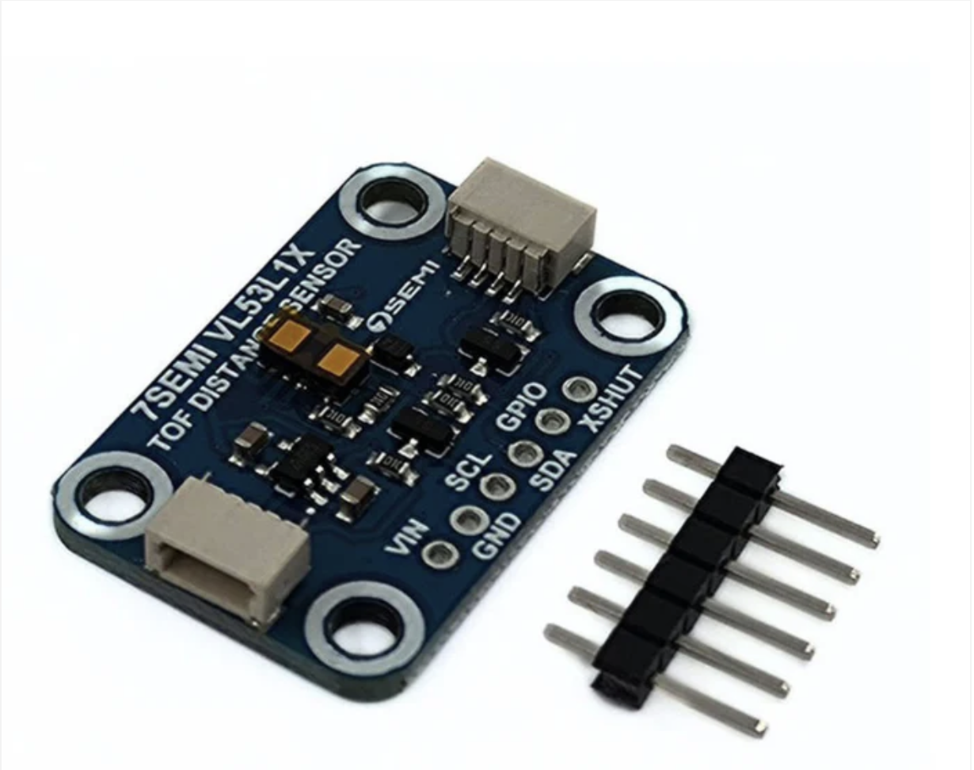
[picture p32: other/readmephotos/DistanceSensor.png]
Distance Sensor
      
    </td>
    <td width="50%" style="text-align: left; vertical-align: top;">
      <h3>VL53L1X Specifications:</h3>
      <li>Operating Voltage: 3.3V </li>
      <li>Range: 4cm to 4m</li>
      <li>Resolution: 1mm</li>
    </td>
  </tr>
  <tr>
    <td width="50%" style="text-align: left;">
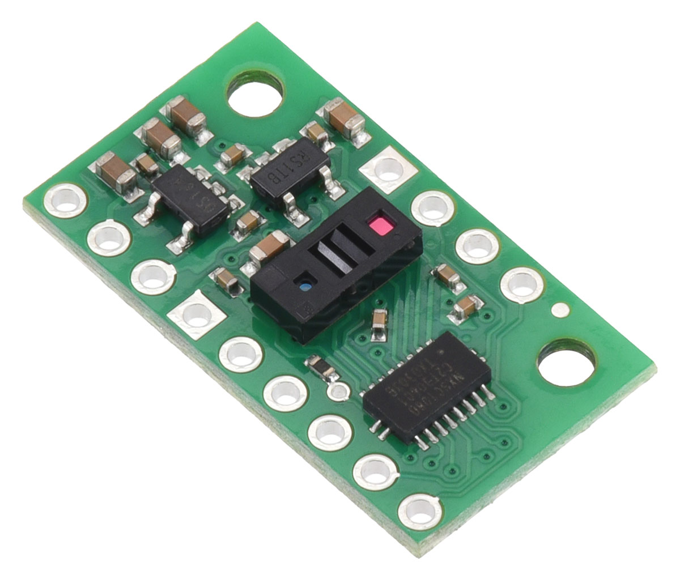
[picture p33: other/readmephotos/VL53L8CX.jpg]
      
    </td>
    <td width="50%" style="text-align: left; vertical-align: top;">
      <h3>VL53L8CX Specifications:</h3>
      <li>Operating Voltage: 3.2V to 5.5V </li>
      <li>Range: 2cm to 4m</li>
      <li>Resolution: 1mm</li>
    </td>
  </tr>  
  <tr>
    <td width="50%" style="text-align: left;">
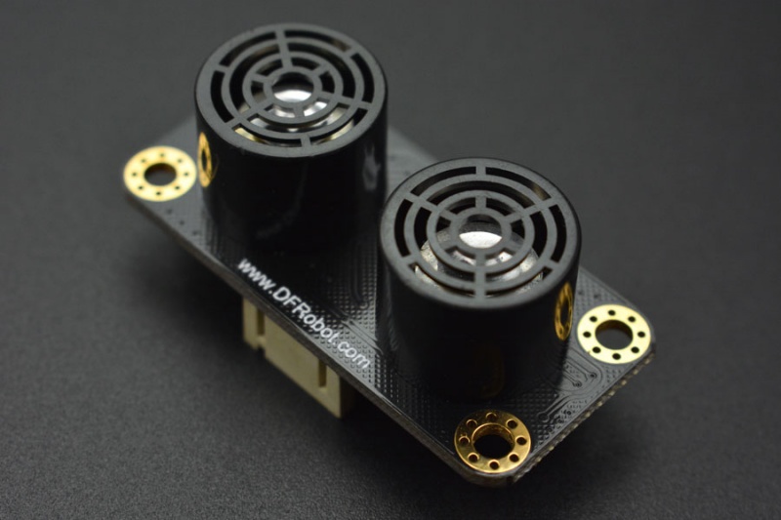
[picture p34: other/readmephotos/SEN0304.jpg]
      
    </td>
    <td width="50%" style="text-align: left; vertical-align: top;">
      <h3>URM09 Specifications:</h3>
      <li>Operating Voltage: 3.3V to 5.5V</li>
      <li>Range: 2cm to 5m</li>
      <li>Resolution: 1cm</li>
    </td>
  </tr>
</table>

**Alternatives considered**

Along with the Ultrasonic and VL53L1X sensors, we also considered LiDAR sensors to help map the game field. In the end, though, we decided to pass on this, as LiDAR sensors are too expensive. Adding a single LiDAR sensor could have increased the robot's cost by nearly 40%. Additionally, at the short ranges relevant to this game field, our existing ultrasonic and ToF sensors already provide sufficient accuracy, so LiDAR would not have meaningfully improved the robot’s accuracy.

**Potential Improvements**

- Use a lidar sensor for a complete 2D image of the surroundings

## Multiplexer

All four of our distance sensors share the same I²C address. Our CJMCU TCA9548A multiplexer splits the  distance sensors into separate channels so only one device is active at a time. This gives each device a “virtual” unique address, letting them coexist without conflict.

<table>
  <tr>
    <td width="50%" style="text-align: left;">
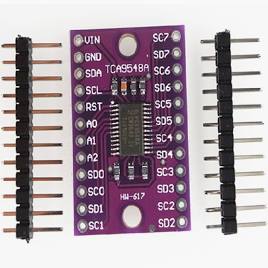
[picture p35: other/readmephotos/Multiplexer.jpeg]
      
    </td>
    <td width="50%" style="text-align: left; vertical-align: top;">
      <h3>Specifications:</h3>
      <li>Model Number: CJMCU TCA9548A </li>
      <li>No. of Channels: 8 </li>
    </td>
  </tr>
</table>

## Bringing it all together

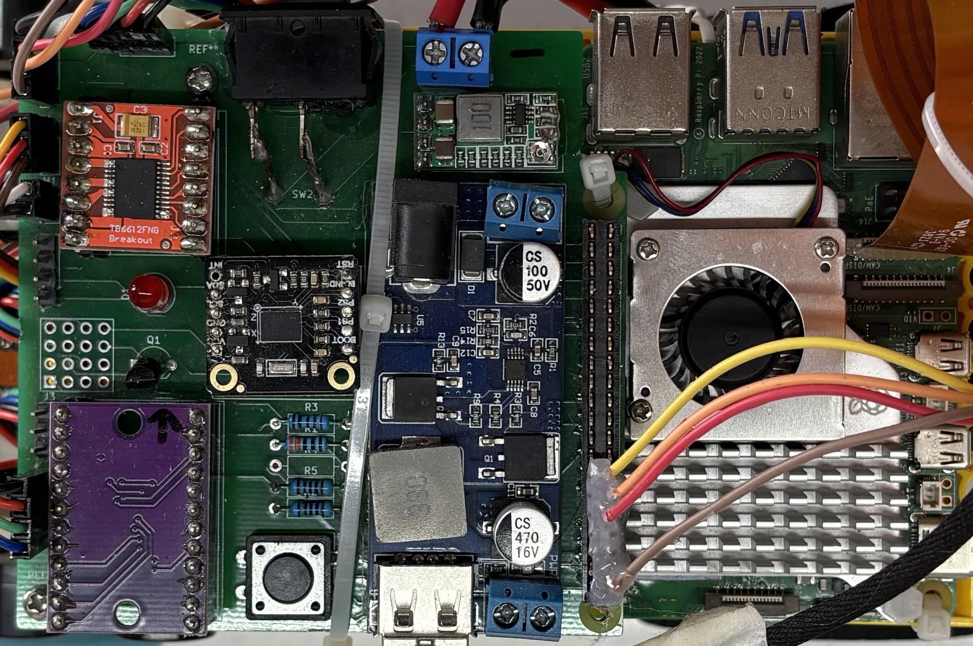
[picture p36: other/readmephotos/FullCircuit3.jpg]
Robot Circuit


**A full wiring diagram is shown in the screenshot below, and available at models/PCB/~Untitled.kicad_sch**

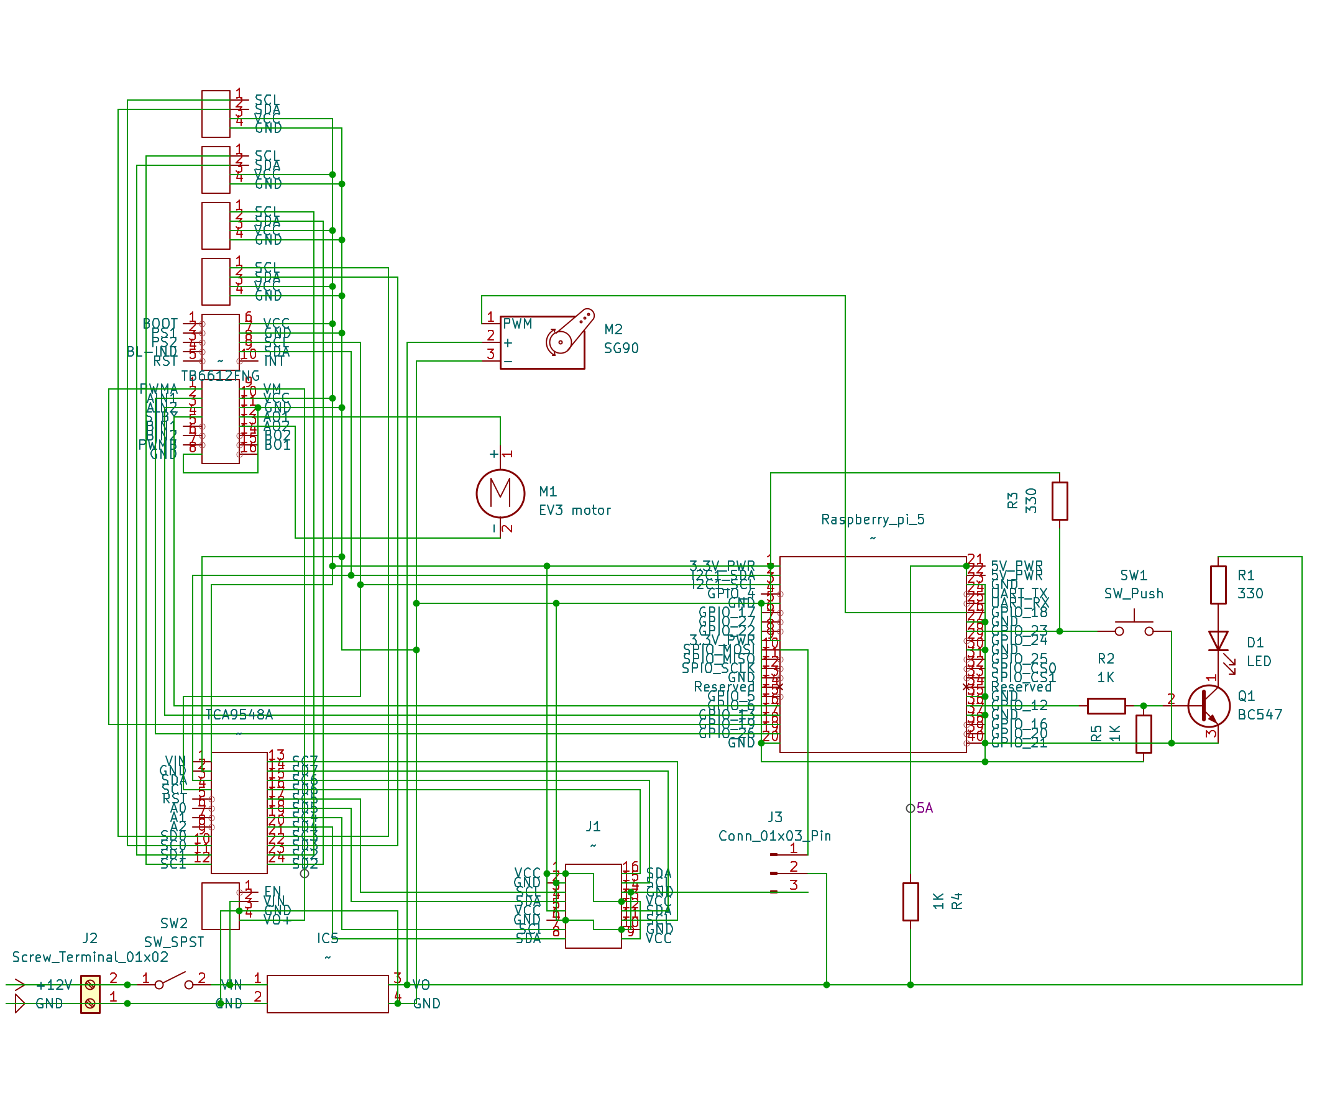
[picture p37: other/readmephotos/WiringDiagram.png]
WiringDiagram


## Code for sensors

### IMU (Gyroscope) - BNO055

Measures the robot's heading (direction) using a combination of gyroscope, accelerometer, and magnetometer sensors.

#### Initialization

```python
def initialize():
    """Initializes the BNO055 sensor."""
    global sensor
    
    try:
        i2c = board.I2C()
        sensor = adafruit_bno055.BNO055_I2C(i2c)
        sensor.mode = adafruit_bno055.NDOF_MODE  # 9-DOF mode
        time.sleep(1)  # Let sensor boot up
        
        print(f"INFO: Gyro (BNO055) Initialized. Temp: {sensor.temperature}°C")
        print(f"INFO: Calibration status: {sensor.calibration_status}")
        return True
    except Exception as e:
        print(f"WARNING: Gyro disabled. Could not initialize: {e}")
        sensor = None
        return True
```

**Explanation:** We initialize the BNO055 on the I2C bus and set it to NDOF mode (9-Degree of Freedom), which uses all three sensors together for accurate heading measurement.

#### Reading Heading

```python
def get_heading():
    """Returns the current heading (yaw) in degrees."""
    if sensor:
        try:
            heading, _, _ = sensor.euler  # Get yaw (heading) from Euler angles
            if heading is not None:
                return heading
        except Exception:
            return None
    return None

def get_initial_heading(num_readings=20):
    """Gets an averaged, stable initial heading."""
    if not sensor:
        return 0.0
    
    print("INFO: Acquiring initial heading...")
    readings = []
    for _ in range(num_readings):
        yaw = get_heading()
        if yaw is not None:
            readings.append(yaw)
        time.sleep(0.05)
    
    if readings:
        initial_heading = np.mean(readings)
        print(f"INFO: Gyro zero point set to: {initial_heading:.2f} degrees.")
        return initial_heading
    return 0.0
```

**Explanation:** The BNO055 returns Euler angles (heading, roll, pitch). We extract the heading (yaw) which tells us which direction the robot is facing. We average multiple readings at startup to get a stable initial heading.

---

### Camera - Raspberry Pi Camera Module 3

Captures video frames for obstacle detection and color identification using computer vision.

#### Initialization

```python
def initialize():
    """Initializes the Picamera2."""
    global picam2
    try:
        picam2 = Picamera2()
        cam_config = picam2.create_preview_configuration(
            main={
                "format": "RGB888",
                "size": (2304, 1296),  # High resolution for processing
            },
            lores={
                "size": (640, 360),    # Low resolution for fast processing
                "format": "RGB888"
            },
            controls={
                "ExposureTime": 8000,  # Exposure time in microseconds
                "FrameRate": 56,       # Frames per second
            }
        )
        picam2.configure(cam_config)
        picam2.start()
        time.sleep(1.0)
        print("INFO: Camera Initialized.")
        return True
    except Exception as e:
        print(f"FATAL: Camera failed to initialize: {e}")
        return False
```

**Explanation:** We set up the camera with two resolutions: high resolution (2304×1296) for detailed processing and low resolution (640×360) for fast real-time processing. We also set exposure time and frame rate for consistent image quality.

#### Capturing Frames

```python
def capture_frame():
    """Captures and returns a single frame from the camera."""
    if picam2:
        frame = picam2.capture_array("lores")  # Get low-res frame for speed
        return frame
    return None
```

**Explanation:** We capture frames from the low-resolution stream for fast processing. This lets us run obstacle detection at 30 FPS without slowing down the robot.

### Distance Sensors - VL53L1X

Measures distance to walls and obstacles using time-of-flight (ToF) technology. Four sensors are mounted on the front, back, left, and right.

#### Initialization

```python
def initialise():
    """Initializes the I2C bus, multiplexer, and all distance sensors."""
    global _i2c_main, _mux, _sensors, _sensor_types
    
    try:
        _i2c_main = busio.I2C(board.SCL, board.SDA)
    except Exception as e:
        print(f"FATAL: Could not initialize I2C bus. Error: {e}")
        return False
    
    try:
        _mux = adafruit_tca9548a.TCA9548A(_i2c_main, address=0x70)
        print("INFO: TCA9548A Mux found at address 0x70.")
    except ValueError:
        print("WARNING: TCA9548A Mux not found.")
        _mux = None
    
    # Probe each channel for sensors
    if _mux:
        print("INFO: Probing for sensors on mux channels...")
        for i in range(8):
            channel_bus = _mux[i]
            
            try:
                vl53_sensor = adafruit_vl53l1x.VL53L1X(channel_bus)
                vl53_sensor.distance_mode = 1
                vl53_sensor.timing_budget = 50
                vl53_sensor.start_ranging()
                _sensors[i] = vl53_sensor
                _sensor_types[i] = 'VL53L1X'
                print(f"  - SUCCESS: VL53L1X found on channel {i}.")
            except (ValueError, OSError):
                print(f"  - INFO: No sensor found on channel {i}.")
    
    print("INFO: Sensor initialization complete.")
    return True
```

**Explanation:** We initialize the I2C bus and the TCA9548A multiplexer. The multiplexer lets us connect 4 sensors with the same I2C address by switching between channels. We probe each channel and initialize any VL53L1X sensors we find.

#### Reading Distance

```python
def get_distance(channel):
    """Reads the distance from a sensor on a specific channel."""
    if channel not in _sensors:
        return None
    
    sensor = _sensors[channel]
    
    try:
        if sensor.data_ready:  # Check if new data is available
            distance_cm = sensor.distance
            sensor.clear_interrupt()
            return distance_cm * 10.0 if distance_cm is not None else None
        return None  # No new data yet
    except (OSError, IOError):
        print(f"I/O Error on channel {channel}. Sensor may be disconnected.")
        return None
```

**Explanation:** We check if the sensor has new data ready. If it does, we read the distance in centimeters and convert it to millimeters. If no new data is ready, we return None immediately without blocking.

# Obstacle Management

## Open Challenge Navigation Algorithm

Navigate 3 laps using camera-based wall detection steering straight in the straight sections. Steer according to the driving section in the corner section. Count turns using orange lines. Stop after 12 turns.

### How it works

1. Detect black walls using HSV color masks
2. Calculate left vs right wall area
3. Steer toward bigger wall (proportional steering)
4. Detect orange lines for turn counting
5. Execute sharp turns when close wall detected
6. Stop after 12 turns

### Flowchart

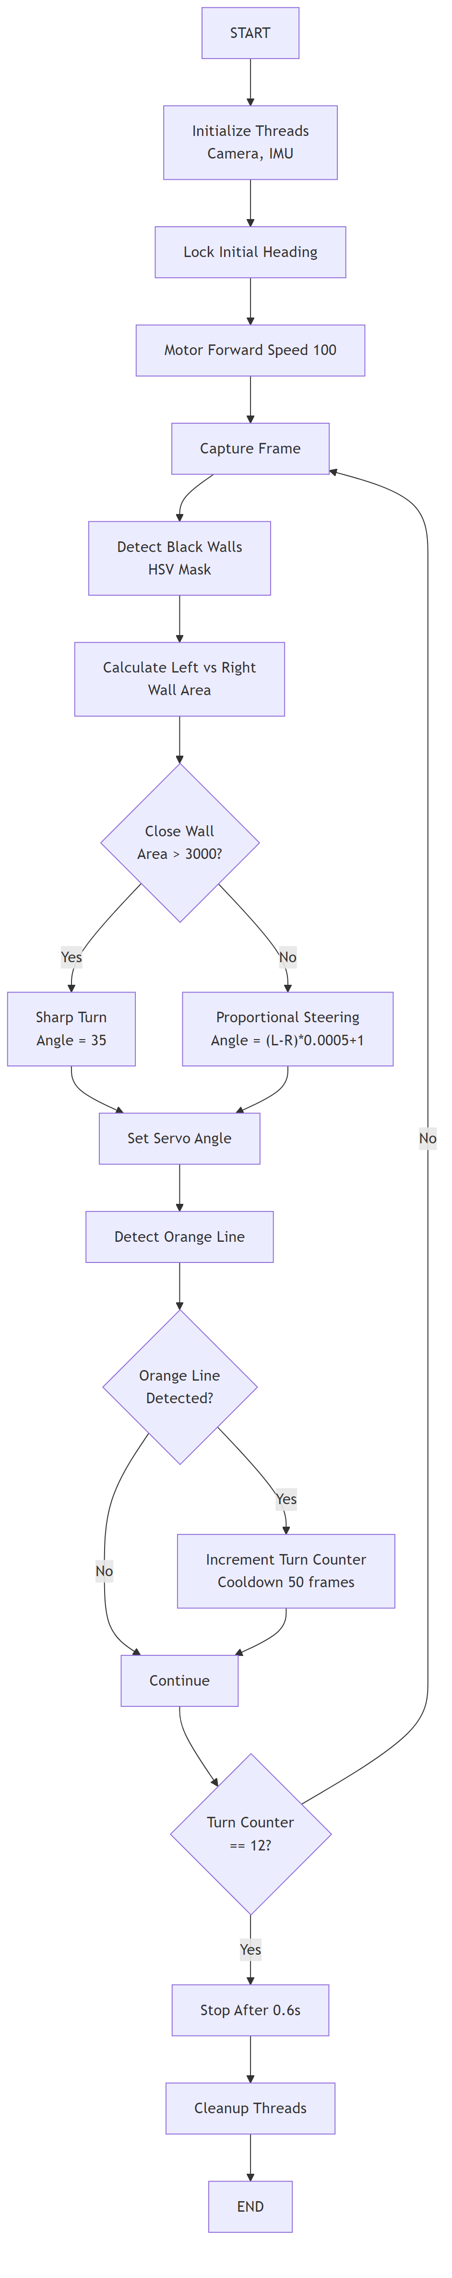
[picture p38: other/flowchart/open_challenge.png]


### Steering

- Calculate difference between two wall areas
- If one side wall disappears, means we are in a turn, turn sharply towards the other side
- Otherwise turn with regular Kp=0.0005

#### Code

```python
left_pixel_size = sum(obj['area'] for obj in detected_walls if 'left' in obj['type'])
right_pixel_size = sum(obj['area'] for obj in detected_walls if 'right' in obj['type'])

# If one side wall disappears, turn sharply towards the other side
if left_pixel_size < 100 and right_pixel_size > 100:
    right_pixel_size += 25000
elif right_pixel_size < 100 and left_pixel_size > 100:
    left_pixel_size += 25000
              
angle = ((left_pixel_size - right_pixel_size) * 0.0005)
```

### Turn Counting
- Detect orange lines in specific ROI
- Keep history of last 4 frames
- Increment counter on no line → line transition
- Use 50-frame cooldown to prevent double-counting

#### Code

```python
orange_detection_history = deque([False] * 4, maxlen=4)
cooldown_frames = 0
orange_detected_this_frame = bool(detections['detected_orange'])
orange_detection_history.append(orange_detected_this_frame)

if cooldown_frames > 0:
    cooldown_frames -= 1
elif not orange_detection_history[-4] and all(list(orange_detection_history)[1:]):
    turn_counter += 1
    cooldown_frames = 50
```

### Sharp Turn Detection
- If close wall area > 3000 pixels: execute sharp turn
- Angle = ±35 degrees
- Prevents collision

#### Code

```python
close_black_area = sum(obj['area'] for obj in detections.get('detected_close_black', []))
if close_black_area > 3000:
    if left_pixel_size < right_pixel_size:
        angle = -35
    else:
        angle = 35
```

### Potential improvements in Open Navigation Algorithm

- Instead of driving in the center of the lane, drive towards the inner wall which could reduce time further. This requires careful tuning of the turns to avoid hitting the walls.

## Obstacle Challenge Navigation Algorithm

Navigate 3 laps while avoiding colored blocks. Drive left of the green block and right of the red block. Detect the driving direction automatically. Count turns using orange lines. Avoid the magenta parking blocks in all laps. Execute parallel parking just before the vehicle approaches the 13th orange line.

### How it works

1. Detect driving direction (clockwise vs counter-clockwise)
2. Perform initial maneuver (85° turn with scanning)
3. Navigate main loop with block avoidance
4. Count turns using orange/blue lines
5. Execute parking at turn 13

### Flowchart

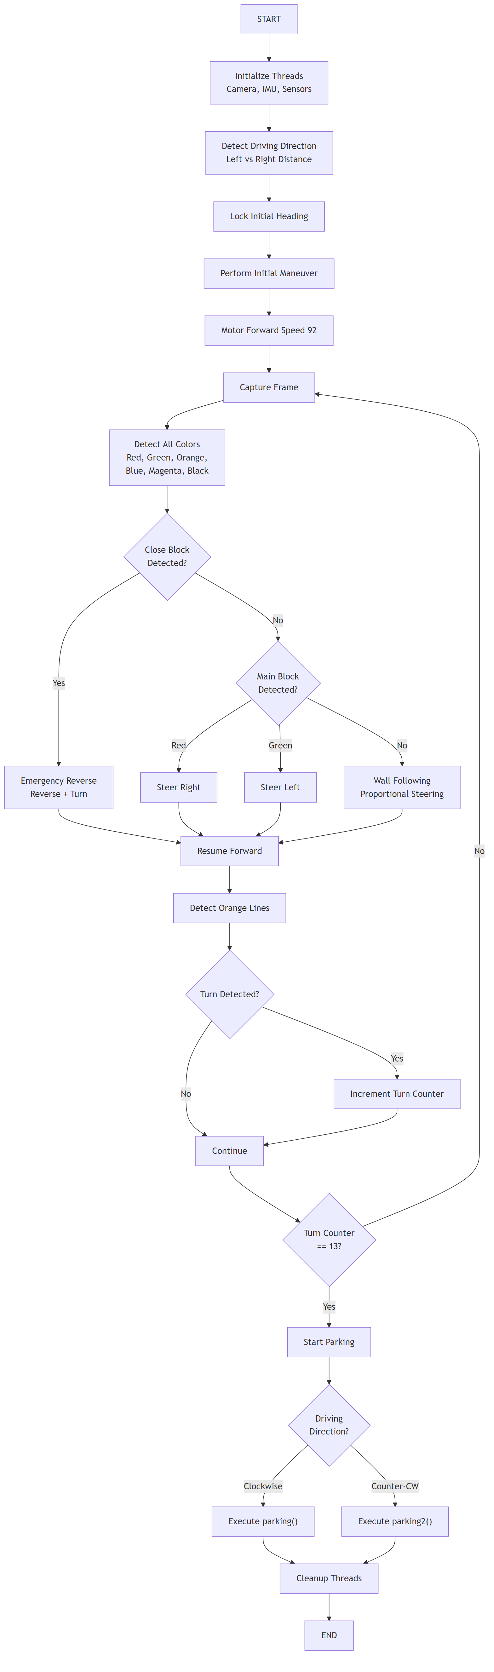
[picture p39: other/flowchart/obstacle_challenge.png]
obstacle_challenge


### Driving Direction Detection

1. Compare left vs right distance sensor readings
2. If left < right: clockwise
3. If right < left: counter-clockwise

#### Code

```python
dist_left = sensor_thread.get_readings()['distance_left']
dist_right = sensor_thread.get_readings()['distance_right']

if dist_left is not None and dist_right is not None:
    if dist_left < dist_right:
        driving_direction = "clockwise"
    else:
        driving_direction = "counter-clockwise"
```

### Initial maneuver

This is the logic for counter clockwise. The logic for clockwise would be mirrored

1. Head out of the parking in slanted orientation
2. scan for blocks (1 second)
3. If red block: reverse and take a right turn
4. If green block: drive forward and take a right turn
5. If no block: drive slanted 1s
6. Return to main loop

#### Flowchart

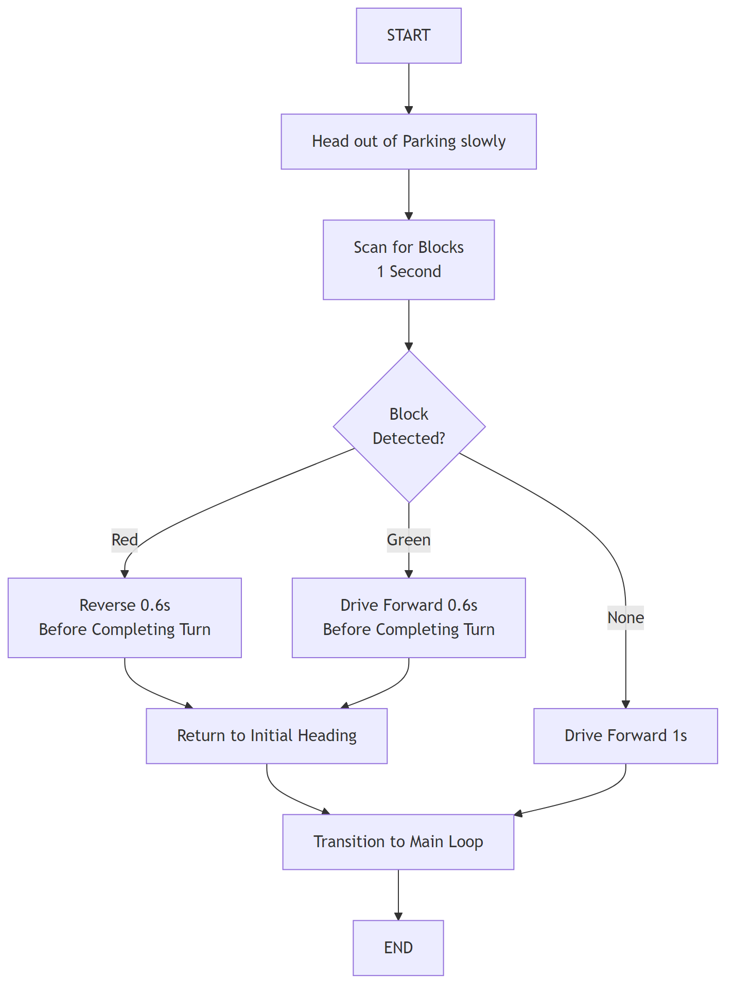
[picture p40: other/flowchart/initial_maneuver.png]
initial_maneuver


#### Code

```python
SCAN_TRIGGER_ANGLE_DEG = 25.0
TOTAL_TURN_ANGLE_DEG = 85.0

motor.forward(MANEUVER_SPEED)
servo.set_angle_unlimited(initial_turn_servo)

while get_angular_difference((INITIAL_HEADING+SCAN_TRIGGER_ANGLE_DEG)%360, 
                             imu_thread.get_heading()) > 10:
    time.sleep(0.01)

motor.brake()
# Scan for blocks
detected_block_color = None
scan_start_time = time.monotonic()

while time.monotonic() - scan_start_time < 1.0:
    frame, frame_counter = camera_thread.get_frame()
    if frame is None: continue
    detections = process_video_frame(frame)
    main_blocks = [b for b in detections.get('detected_blocks', []) if b['type'] == 'block']
    
    if main_blocks and main_blocks[0]['area'] > 1000:
        detected_block_color = main_blocks[0]['color']
        break
```

### **Color Detection**

Detect 6 different colors to identify walls, blocks, turn lines, and parking boundaries. Each color serves a specific purpose in navigation and obstacle avoidance.

1. Convert frame to HSV color space
2. Apply Gaussian blur
3. Create masks for each color
4. Apply ROI masks (region of interest)
5. Find contours (outlines)
6. Filter by minimum area
7. Calculate centroid (center point)

#### Flowchart

color_detection

#### Code

```python
def process_video_frame(frame):
    hsv_frame = cv2.cvtColor(frame, cv2.COLOR_BGR2HSV)
    
    mask_red1 = cv2.inRange(hsv_frame, [0, 150, 80], [10, 255, 255])
    mask_red2 = cv2.inRange(hsv_frame, [175, 150, 80], [180, 255, 255])
    mask_red = cv2.bitwise_or(mask_red1, mask_red2)
    
    mask_green = cv2.inRange(hsv_frame, [36, 50, 70], [89, 255, 255])
    mask_orange = cv2.inRange(hsv_frame, [6, 70, 20], [26, 255, 255])
    mask_magenta = cv2.inRange(hsv_frame, [158, 73, 64], [173, 255, 223])
    mask_blue = cv2.inRange(hsv_frame, [94, 45, 58], [140, 226, 185])
    
    # Apply ROI masks and find contours
    # ... contour detection logic
```

### Regions of Interest

**Why multiple ROIs?**

- Faster processing (less data)
- More accurate (fewer false detections)
- Better performance (40 FPS maintained)

#### 7 ROI Masks

1. **Left Wall ROI** - Detect left wall for steering
2. **Right Wall ROI** - Detect right wall for steering
3. **Inner Left Wall ROI** - Detect inner walls
4. **Inner Right Wall ROI** - Detect inner walls
5. **Main Block ROI** - Detect red/green blocks ahead
6. **Close Block ROI** - Detect blocks very close (emergency)
7. **Line ROI** - Detect orange/blue lines for turns

### Block avoidance

Detect colored blocks (red and green) and execute appropriate maneuvers to avoid them. Handle both emergency situations (very close blocks) and normal avoidance (blocks ahead).

**Close Blocks (Emergency Reverse):**

- Very close to robot
- Execute emergency maneuver: reverse, turn servo, drive forward

**Main Blocks (Steering Avoidance):**
- Ahead of robot but not too close
- Calculate steering to pass correctly:
  - Red: pass from right side
  - Green: pass from left side

#### Flowchart

block_avoidance

#### Code

```python
if detected_blocks:
    is_close_block = False
    for block in detected_blocks:
        if block['type'] == 'close_block':
            is_close_block = True
            if block['color'] == 'red':
                angle = -25
            elif block['color'] == 'green':
                angle = 30
            servo.set_angle(angle)
            motor.reverse(60)
            time.sleep(0.5)
            motor.forward(60)
            servo.set_angle(-angle)
            time.sleep(0.3)
            motor.forward(MOTOR_SPEED)
            break
    
    if not is_close_block:
        block = detected_blocks[0]
        block_color = block['color']
        block_x, block_y = block['centroid']
        
        if block_color == 'red':
            target = 150
            angle = ((block_x - (320 - target)) * 0.09) + 1
        elif block_color == 'green':
            target = 150
            angle = ((block_x - (320 + target)) * 0.1) + 1
```

### Parking logic

Execute parallel parking maneuver in two directions (clockwise and counter-clockwise). Use wall following and magenta block detection to position robot precisely at the parking start point. Then execute a parking maneuver to park parallely between parking boundaries.

1. Drive forward until front sensor close to wall
2. Reverse until back sensor close to wall
3. Drive forward taking a left turn entering the parking section
4. Line following mode by tracking black wall on left side at fixed pixel
5. Stop at the second magenta block
6. Park parallelly with the help of IMU and servo

#### Sketch

parking

### Threading Architecture

Threading allows the robot to process multiple tasks simultaneously:
- Capture camera frames
- Read gyro heading
- Read distance sensors
- Write video to file
- Control motors

#### 4 Threads

**CameraThread:**

- Continuously captures frames (~30 FPS)
- Stores latest frame in memory
- Main loop reads this frame

**ImuThread:**
- Continuously reads gyro heading (~100 Hz)
- Stores latest heading in memory
- Main loop reads this heading

**SensorThread:**
- Continuously reads distance sensors (~50 Hz)
- Stores latest readings in memory
- Main loop reads these readings

**VideoWriterThread:**
- Continuously writes frames to MP4
- Receives frames from main loop
- Writes to disk in background

#### Thread Synchronization
Use locks (mutexes) to prevent simultaneous access to shared data. Only one thread can access data at a time.

### Potential improvements in Obstacle Navigation Algorithm

- Experiment with LAB color detection if it resolves some of the color detection problems we face with HSV
- Use Machine Learning to train a model for navigating around parking blocks within the walls and use this model to drive the robot.
- Use Machine Learning to train a model for parallel parking and use it to park the robot
- Use encoder (instead of time based driving) to park more accurately during parallel parking.

# Engineering Factors

## Design evolution

We started building the robot in mid of January 2025 and here is a timeline of our robot evolution over the last 10 months!

1. We designed our own robot chassis with differential gear axle and steering

   |  |  |
   | ------------------------------------------------------------ | ------------------------------------------------------------ |

2. First prototype of motor attachment with vertical orientation secured by zip ties

   |  |
   | :----------------------------------------------------------: |

3. 3D printed assembly to attach servo motor to steering

   |  |
   | :----------------------------------------------------------: |

4. Mounted Raspberry Pi5 on a cardboad sheet, battery, power converter, axle motor, motor driver and servo motor for steering

   |  |
   | :----------------------------------------------------------: |

5. Adding a camera so that our robot can see!

   |  |
   | :----------------------------------------------------------: |

6. Moving the components to a lego base plate to make it more stable

   |  |
   | :----------------------------------------------------------: |

7. Attaching the lego base plate to the robot chassis along with distance sensors

   |  |
   | :----------------------------------------------------------: |

8. All components connected with wires and bread board power rail for electrical prototyping

   |  |
   | :----------------------------------------------------------: |

9. A jungle of wires!

   |  |  |
   | ------------------------------------------------------------ | ------------------------------------------------------------ |

10. Tied the wires neatly and upgraded the sensors

    |  |      |
    | :----------------------------------------------------------: | ---- |

11. Created a custom PCB to solve the wire mess and to make the connections reliable

    |  |  |
    | ------------------------------------------------------------ | ------------------------------------------------------------ |
    |  |  |

12. Moved to a custom PCB

    |  |  |
    | ------------------------------------------------------------ | ------------------------------------------------------------ |

13. Aligned the battery so that it doesn't protrude outside the robot

    |  |
    | :----------------------------------------------------------: |

## From Nationals to Internationals!

- Changed the driving logic from basic object color detection to consider X axis position of the object, resulting in human like driving
-  Used camera to drive between the walls instead of relying on sensors.
-  Designed custom 3D printed mounts for camera, sensors and servo horn.

|  |  |
| --- | --- |
| Changed the wheels and designed a custom 3D printed camera mount. Moved the camera to vehicle rear to improve FOV. | Designed a custom 3D printed sensor mount for stable mounting of distance sensors. Designed a 3D printed horn coupling for servo motor. |

# Robot construction guide

## 1: Print the 3D parts
- The STL part files for the mounts for servo motor, servo horn, camera base, camera arm and sensors are in the `models/chassis` folder. Recommended settings
  - Material: PLA
  - Infill: 100%

3Dmounts

## 2: Assemble the steering and drive train
- Create the steering assembly using the Lego parts in the photos
- Attach the two rear wheels with a differential gear assembly using Lego gears and axle
- Attach the Lego EV3 medium motor with Lego pins to the chassis
- The Lego motor gears should mesh with the differential gear
- Attach the front wheels

| lego_1_iso | lego_2_front | lego_3_iso |
| :--- | --- | --- |

## 3: Attach the 3D mounts
- Mount the servo on the 3D printed servo motor mount
- Attach the servo horn to the steering with 3D printed servo horn mount
- Attach the servo mount to the chassis using Lego pins
- Attach the Camera base mount to the rear part of the chassis
- Attach the Camera arm mount to the base mount using screws
- Use zip ties if necessary

ChassisWith3dMount

## 4: Fabricate the PCB
- Fabricate the PCB from the KiCAD files in the `models/PCB` folder using KiCAD (https://www.kicad.org/)
## 5: Soldering the electronics and gradual safe startup
- Solder all the headers to the PCB
- Solder the power modules
- Attach the battery and verify if Raspberry Pi5 boots up
- Solder the startup switch and LED and verify if it can be programmed using a test program
- Attach the motor driver module to the header pins and verify if motors can be controlled using a test program
- Attach the multiplexer module to the header pins and verify if sensors can be read using a test program
- Attach the IMU module to the header pins and verify if orientation values can be read using a test program
- Attach the Raspberry Pi5 wide angle camera

FullCircuit3

## 6: Download the code
- Connect the Raspberry Pi5 to a monitor, keyboard and mouse
- Install python dependencies
  - `pip3 install adafruit-circuitpython-bno055`
  - `pip3 install adafruit-circuitpython-tca9548a`
  - `pip3 install adafruit-circuitpython-vl53l1x`
- Download the code from the `src` folder to the Raspberry Pi5
- Run the code!
  - `/src/open_challenge/main.py` for Open challenge
  - `/src/obstacle_challenge/main_v3.py` for Obstacle challenge
## 7: Robot stability
- Run the robot and hopefully should run great!
- If the gears make a grinding noise, it is likely due to the lego components not tightly coupled. Use zip ties to ensure the chassis beams are tightly connected.

# Major challenges faced

### Sensor

One major challenge we faced was in working with the VL53L8CX ToF sensor. We have placed it on the back of our robot to aid in parking, but it was extremely unreliable and onerous to work with during testing. The sensor lacked a dedicated Python library (only providing a C-based library), and refused to communicate through our I²C multiplexer. These limitations made integration unexpectedly difficult for us.

To connect this sensor, we first created our own Python version of the C library. Then, we moved the sensor to a secondary I²C bus to bypass the multiplexer and eliminate communication conflicts. 

The sensor failed roughly once in every twenty readings. We wanted to make the sensor more reliable. To solve, this, we went deep into the technical documentation of the sensor and realised that the Raspberry Pi ports were configured as pull down instead of pull ups. Since this fix the sensor has never failed.

### Camera

Another major challenge arose when we tried to use a fish-eye lens in place of our camera for image detection. We wanted to use a fish-eye lens, as it had a wider Field Of View (195 degrees) than our Raspberry Pi Camera Module 3 (120 degrees)

Unfortunately, this didn’t work out. The fish-eye camera has a circular lens, which means all images we received were distorted and circular. This made it difficult to calculate their area, which hindered accuracy. Oftentimes, blocks would be detected either too early or too late. While we could have attempted to add circular ROIs, this would have added significant complexity to the bot and would have required extensive tuning.

# How we used Github

Our team used Github to store all of our code such that it is accessible to all team members and to those who wish to use this repository in the future. We have made frequent commits to this repository, and this repository stands as testament to our efforts, and the process of design as a whole

### The Structure of This Repository

* `t-photos` contains 2 photos of the team (an official one and one funny photo with all team members)
* `v-photos` contains 6 photos of the vehicle (from every side, from top and bottom)
* `video` contains the video.md file with the link to a video where driving demonstration exists
* `schemes` contains several schematic diagrams of the electronic components, chassis, circuit diagram and 3D part images
* `src` contains code of control software for all components which were programmed to participate in the competition
* `models` is for the design files for models used for 3D printing and PCB manufacturing
* `other` is for other files which can be used to understand how to prepare the vehicle for the competition.

### Source code organization

```python
src/
├── motors/
│   ├── motor.py          # DC motor control
│   ├── servo.py          # Servo steering control
│   └── test_pwm.py       # PWM testing
├── sensors/
│   ├── camera.py         # Camera module interface
│   ├── distance.py       # Distance sensor reading
│   ├── bno055.py         # IMU/Gyro sensor
│   ├── color_tuning.py   # Color detection tuning
│   └── vl53l1x.py        # ToF sensor driver
├── open_challenge/
│   ├── main.py           # Open challenge algorithm
│   └── config.py         # Configuration parameters
└── obstacle_challenge/
    ├── main_v3.py        # Obstacle challenge algorithm
    ├── config.py         # Configuration parameters
    └── nationals/        # National competition version
```

### 

# Bill of Materials

| Component | Make and Model | Price | Quantity | Total Price | Component Purchase Link |
|---|---|---|---|---|---|
| Single Board Computer | Raspberry Pi 5 (8GB) | 8291 | 1 | 8291 | https://robu.in/product/raspberry-pi-5-model-8gb/ |
| Camera Module | Raspberry Pi Camera Module 3 | 3551 | 1 | 3551 | https://www.silverlineelectronics.in/products/copy-of-test-1 |
| IMU Sensor | BNO055 9-DOF Intelligent Sensor | 2001 | 1 | 2001 | https://robu.in/product/df-robot-febno055-intelligent-9-axis-sensor-rmion-bno055-intelligent-9-axis-sensor-breakout/ |
| Distance Sensor | VL53L1X ToF Distance Sensor (4-400cm range) | 668 | 1 | 668 | https://robocraze.com/products/vl53l1x-tof-distance-sensor-breakout-with-4-meter-range-7semi |
| Distance Sensor | VL53L8CX ToF Distance Sensor (2-400cm range) | 1892 | 1 | 1892 | https://www.fabtolab.com/pololu-3419-vl53l8cx-time-of-flight-8-8-zone-distance-sensor-carrier-voltage-regulators-400cm-max |
| Distance Sensor | URM09 Ultrasonic Distance Sensor | 1150 | 2 | 2300 | https://wiki.dfrobot.com/URM09_Ultrasonic_Sensor_(Gravity-I2C)_(V1.0)_SKU_SEN0304 |
| I2C Multiplexer | CJMCU TCA9548A 8-Channel I2C Multiplexer | 75 | 1 | 75 | https://robu.in/product/cjmcu-tca9548a-i2c-8-channel-multiple-extensions-development-board/ |
| Servo Motor | TowerPro SG90 9g Mini Servo | 94 | 1 | 94 | https://robu.in/product/towerpro-sg90-9g-mini-servo-9-gram/ |
| Drive Motor | LEGO EV3 Medium Motor | 1500 | 1 | 1500 | https://www.brickowl.com/catalog/lego-mindstorms-ev3-medium-motor-99455 |
| Motor Driver | TB6612FNG Dual Motor Driver Module | 161 | 1 | 161 | https://robu.in/product/motor-driver-tb6612fng-module-performance-ultra-small-volume-3-pi-matching-performance-ultra-l298n/ |
| Battery | Bonka 11.1V 2200mAh 35C LiPo Battery | 1959 | 1 | 1959 | https://www.flyrobo.in/11.1v-2200mah-35c-3s1p-bonka-lipo-battery-bonka-high-capacity-lipo-battery |
| Voltage Converter | XY-3606 24V/12V to 5V 5A Power Module | 160 | 1 | 160 | https://robu.in/product/24v-12v-to-5v-5a-power-module-dc-dc-xy-3606-power-converter/ |
| Mechanical Components | LEGO Mindstorms EV3 (some parts)| 2000 | 1 | 2000 | https://www.brickowl.com/catalog/lego-mindstorms-ev3-set-31313 |
| Differential Gear | LEGO Differential Gear | 150 | 1 | 150 | https://www.brickowl.com/catalog/lego-differential-gear-casing-with-bevel-gear-on-end-with-open-center-62821 |
| Custom PCB | Custom Designed PCB | 6579 | 1 | 6579 | https://www.pcbpower.com/ |
| 3D Printed Parts | Servo mounts, Sensor mount, Camera mounts | 200 | 5 | 1000 |  |
| Total |  |  |  | 32381 | INR |

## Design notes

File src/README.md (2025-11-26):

# Greenbotics Control Software (`src`)

This folder contains all Python code that runs on the Raspberry Pi 5 to control the Greenbotics robot for the WRO Future Engineers 2025 Open and Obstacle challenges. This code is split into smaller modules for sensors, motors and high-level challenge logic.

## Layout

- `open_challenge/` – high-level logic for the Open Challenge (`main.py`).
- `obstacle_challenge/` – high-level logic for the Obstacle Challenge(`main_v3.py`).
- `sensors/` – drivers/wrappers for the IMU (BNO055), distance sensors (VL53L1X / VL53L8CX / URM09) and camera (Picamera2 + OpenCV).
- `motors/` – drive motor and steering (servo) control.

## Python dependencies

The control software uses the following third‑party Python libraries:

- `numpy` – numerical processing for vision and sensor fusion.
- `opencv-python` / `python3-opencv` – image processing and computer vision.
- `gpiozero` and `lgpio` – GPIO access and motor driver control.
- `rpi-hardware-pwm` – hardware PWM for the drive motor and steering servo.
- `picamera2` and `libcamera` – camera access on Raspberry Pi.
- `adafruit-blinka` – provides `board`/`busio` for CircuitPython drivers on Linux SBCs.
- `adafruit-circuitpython-bno055` – IMU (orientation) sensor driver.
- `adafruit-circuitpython-tca9548a` – I2C multiplexer driver.
- `adafruit-circuitpython-vl53l1x` – VL53L1X ToF distance sensor driver.
- `adafruit-circuitpython-busdevice` – shared I2C device helpers.
- `adafruit-circuitpython-neopixel-spi` – SPI NeoPixel (WS2812-compatible) LED control used via `neopixel_spi`.

Standard-library modules such as `time`, `threading`, `ctypes`, `json`, `traceback`, etc. are also used but do not require separate installation.

## How to install dependencies (Raspberry Pi OS)

On a Raspberry Pi (recommended environment), first install the system-level packages:

```bash
sudo apt update
sudo apt install -y \
  python3 python3-pip python3-opencv python3-numpy \
  python3-gpiozero python3-libcamera python3-picamera2 python3-lgpio
```

Then install the Python libraries that are typically provided via `pip`:

```bash
pip3 install \
  numpy opencv-python gpiozero lgpio rpi-hardware-pwm \
  adafruit-blinka adafruit-circuitpython-bno055 \
  adafruit-circuitpython-tca9548a adafruit-circuitpython-vl53l1x \
  adafruit-circuitpython-busdevice adafruit-circuitpython-neopixel-spi
```

On non-Raspberry-Pi Linux systems, you can generally install the same Python packages with `pip3`, but `picamera2`/`libcamera` support and GPIO access may require additional board-specific setup.

## Running the control software

From the repository root, run the main programs using the `src` package:

```bash
cd /path/to/greenbotics

# Obstacle Challenge
python3 -m src.obstacle_challenge.main_v3

# Open Challenge
python3 -m src.open_challenge.main
```

Make sure all hardware is wired as described in the top-level `README.md` and that the commands above are executed on the robot’s Raspberry Pi.

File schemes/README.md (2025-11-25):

This directory contains the following schematic diagrams

- Wiring diagrams
- 3D printed parts diagrams
- Base chassis design diagrams

</br>

- Circuit Diagram

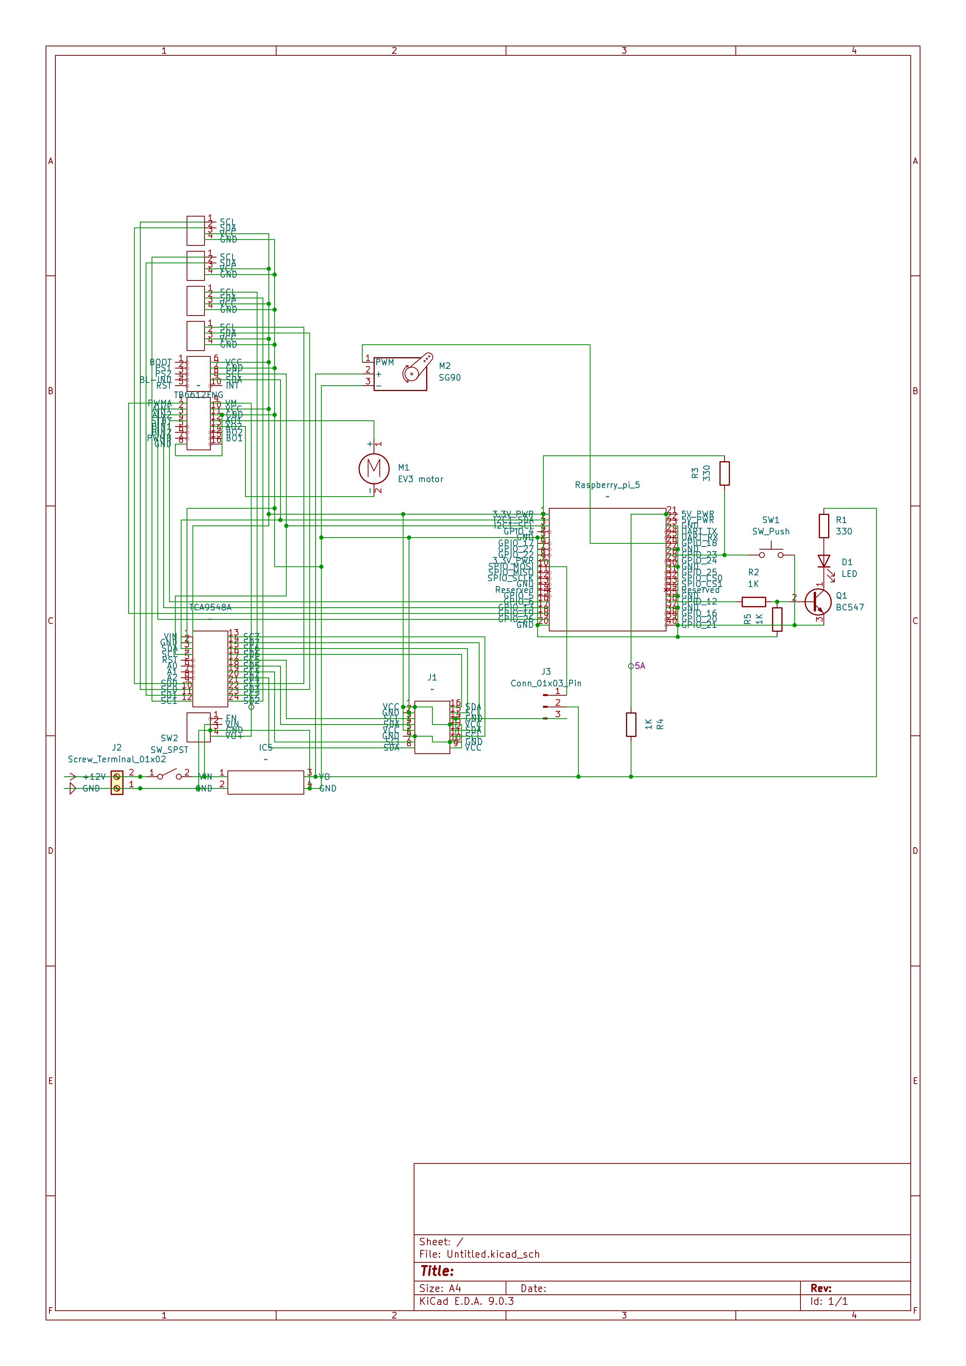
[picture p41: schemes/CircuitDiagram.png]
CircuitDiagram


- Motor Connection Diagram

MotorConnectionDiagram

- Camera arm mount

CameraMountArm
 
- Camera base mount

CameraMountBase
 
- Sensor mount

SensorMount

- Servo motor mount

ServoMount

- Servo horn mount

ServoHornMount

- Chassis step 1 (top)

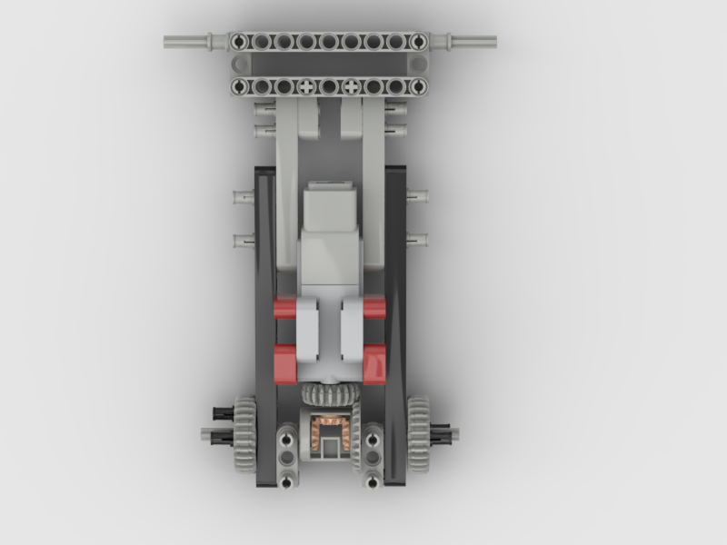
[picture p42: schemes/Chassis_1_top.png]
Chassis_1_top


- Chassis step 1 (bottom)

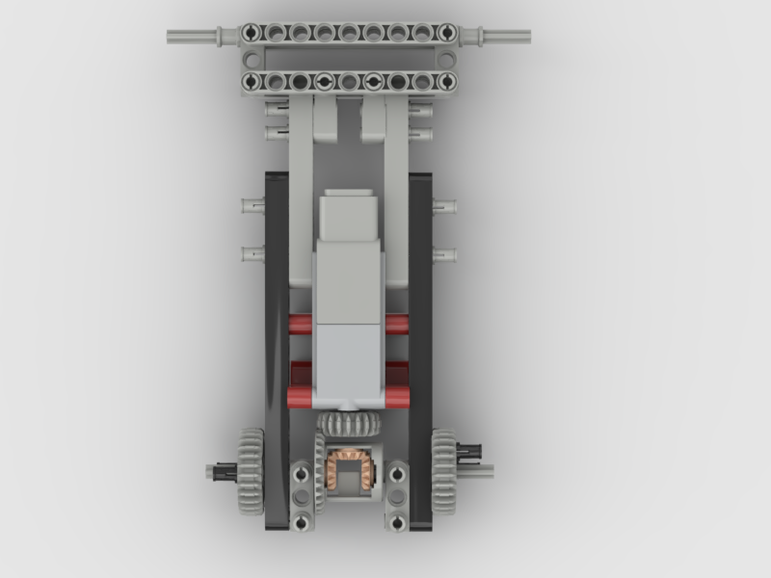
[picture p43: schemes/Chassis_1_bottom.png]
Chassis_1_bottom


- Chassis step 1 (iso)

Chassis_1_iso

- Chassis step 2 (front)

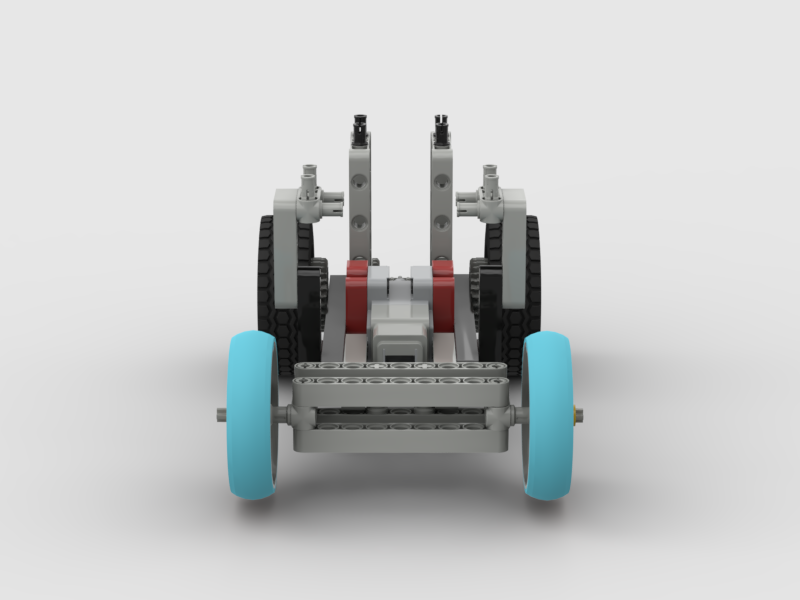
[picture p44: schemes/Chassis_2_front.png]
Chassis_2_front


- Chassis step 3 (iso)

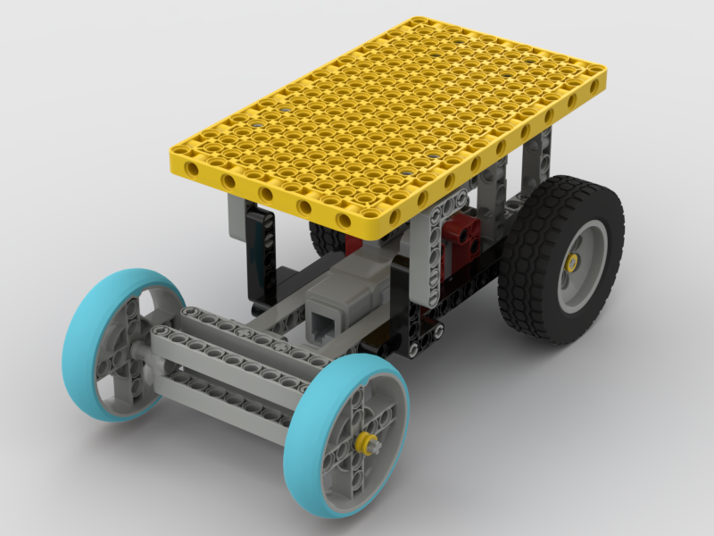
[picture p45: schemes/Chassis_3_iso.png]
Chassis_3_iso


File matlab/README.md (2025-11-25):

# MATLAB WRO Simulation Report

## Table of Contents
- [Problem Statement](#problem-statement)
- [Project Objective](#project-objective)
- [Key Features of the Model](#key-features-of-the-model)
- [Simulation Architecture](#simulation-architecture)
  - [Arena Layer](#arena-layer)
  - [Robot Layer](#robot-layer)
  - [Navigation Layer](#navigation-layer)
  - [Camera Layer](#camera-layer)
- [MATLAB Simulation Screenshots](#matlab-simulation-screenshots)
- [MATLAB Code](#matlab-code)
- [Methodology](#methodology)
  - [Stage 1 – Arena Geometry](#stage-1--arena-geometry)
  - [Stage 2 – Texture Mapping](#stage-2--texture-mapping)
  - [Stage 3 – Robot Modeling](#stage-3--robot-modeling)
  - [Stage 4 – Path and Waypoints](#stage-4--path-and-waypoints)
  - [Stage 5 – Steering Physics](#stage-5--steering-physics)
  - [Stage 6 – Wiggle Noise](#stage-6--wiggle-noise)
  - [Stage 7 – Camera Simulation](#stage-7--camera-simulation)
- [Conclusion](#conclusion)

---

## Problem Statement

Testing robot navigation directly on the physical WRO arena is slow, inconsistent, and prone to human and hardware error. During development, small mistakes—such as incorrect turning radius, heading overshoot, or path drift—consume valuable time and may damage motors or sensors. 

To solve this, our objective was to build a realistic digital twin of the WRO Open Challenge arena using MATLAB. This virtual environment allows us to test:

- Robot movement
- Steering and heading corrections
- Cornering behavior
- Wiggle / vibration effects
- Camera perspectives
- Strategy around the inner square

—all without touching the physical robot.

## Project Objective

The purpose of this MATLAB module is to:

1. Simulate the WRO 2025 arena accurately in 3D and 2D.
2. Replicate the robot's movement using realistic physics (car-like steering).
3. Provide two essential debug views:
   - A front chase camera (like a real robot camera)
   - A top-down map showing path, walls, and waypoints
4. Visualize the WRO arena mat using the original PNG/JPEG texture.
5. Test path-following logic around the central square.
6. Add noise/wiggle to replicate real hardware behaviour.
7. Allow rapid iteration before deploying code to the actual robot.

## Key Features of the Model

- ✔ Accurate 3×3 m WRO arena
- ✔ Real arena texture mapped using wro.jpeg
- ✔ 3D walls + 2D outlines
- ✔ Robot rendered as a 3D cube
- ✔ Waypoint navigation around the central square
- ✔ Car-like steering (limited turning rate)
- ✔ Adjustable speed, turning gain, wiggle amount
- ✔ Persistent front camera perspective
- ✔ Smooth animation using MATLAB's rendering loop

## Simulation Architecture

### Arena Layer

- Outer walls (3D & 2D)
- Inner square wall (3D & 2D)
- Arena floor textured with the official WRO mat

### Robot Layer

- 3D cube robot body
- Red dot in top view
- Position updated each time step
- Heading updated based on steering angle
- Wiggle noise added to simulate vibration

### Navigation Layer

- Four waypoints around the inner square
- Robot follows path anticlockwise
- When near a waypoint → switches to next
- Steering direction calculated using angle error

### Camera Layer

- Virtual chase camera follows the robot
- Looks ahead toward a future point
- Has adjustable FOV, height, and offset

## MATLAB Simulation Screenshots

### Front Camera View

**Figure 1** – Robot front-camera / chase-view simulation in MATLAB.

Front Camera View

### Official WRO Mat Texture

Official WRO mat used as texture in simulation.

WRO Mat Texture

## MATLAB Code

[MATLAB code available - Click here to view the code](https://github.com/Devansh-awat/greenbotics/blob/main/matlab/open_challenge.m)

## Methodology

### Stage 1 – Arena Geometry

The arena dimensions and walls were defined in meters to match WRO specifications. Cuboid meshes were used to create walls, ensuring they render correctly in the 3D view.

### Stage 2 – Texture Mapping

The official WRO mat was loaded and scaled per meter. This converts pixel coordinates into real-world coordinates.

### Stage 3 – Robot Modeling

The robot was modeled as a simple rigid cube. Orientation changes are handled using a rotation matrix.

### Stage 4 – Path and Waypoints

A rectangle around the inner square was chosen as the baseline path.

### Stage 5 – Steering Physics

Instead of teleporting or rotating instantly, the robot:

- Slowly adjusts heading
- Limits turn rate (max 140° per second)
- Moves at 0.12 m/s

This models a real car-like system.

### Stage 6 – Wiggle Noise

Random Gaussian noise simulates motor vibration, wheel imbalance, or surface friction.

### Stage 7 – Camera Simulation

A dynamic camera was positioned behind the robot and updated every frame.

## Conclusion

The developed MATLAB simulation successfully models the WRO 2025 arena, robot kinematics, and camera perspectives in a realistic and structured way. By providing visual debugging, real mat texture, and steering physics, the system acts as a complete digital twin for testing strategies before deploying to the physical robot. This reduces trial-and-error, saves time during practice, and significantly improves reliability and planning.

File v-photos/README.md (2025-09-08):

Vehicle's photos
====

This directory contains 6 photos of the vehicle

Top
Top

Bottom
Bottom

Front
Front

Back
Back

Left
Left

Right
Right

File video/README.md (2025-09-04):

Video
====

This directory contains the video.md file with a URL to the YouTube video showing the vehicle driving autonomously.

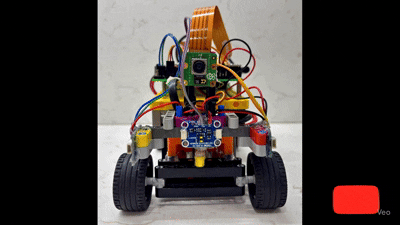
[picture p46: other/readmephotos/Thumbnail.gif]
"Video To Our Robot" (https://www.youtube.com/watch?v=yn76rDG4Hm4)


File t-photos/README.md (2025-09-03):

Team's photos
====

This directory contains photos of our team

The official one !
GreenboticsTeamPic

The funny one :)
GreenboticsClowns

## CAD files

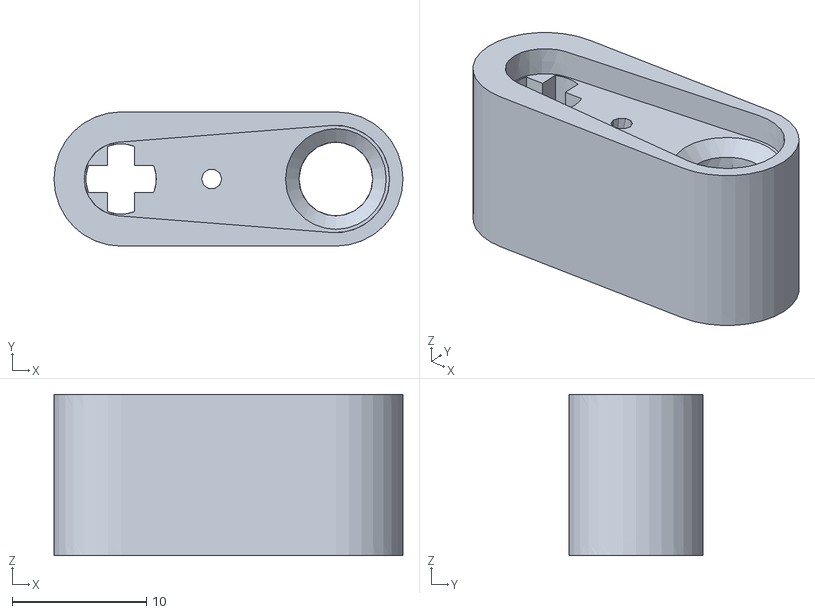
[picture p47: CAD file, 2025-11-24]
models/chassis/ServoHorn3D.stl
26.0 x 10.0 x 12.0

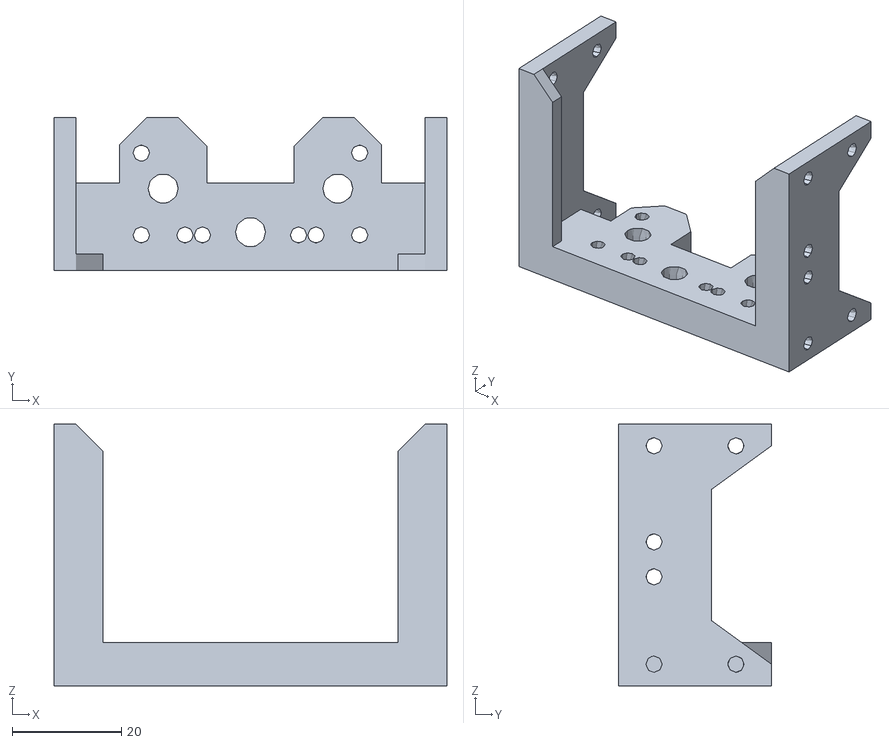
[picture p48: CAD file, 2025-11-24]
models/chassis/SensorMount.stl
72.0 x 28.0 x 48.0

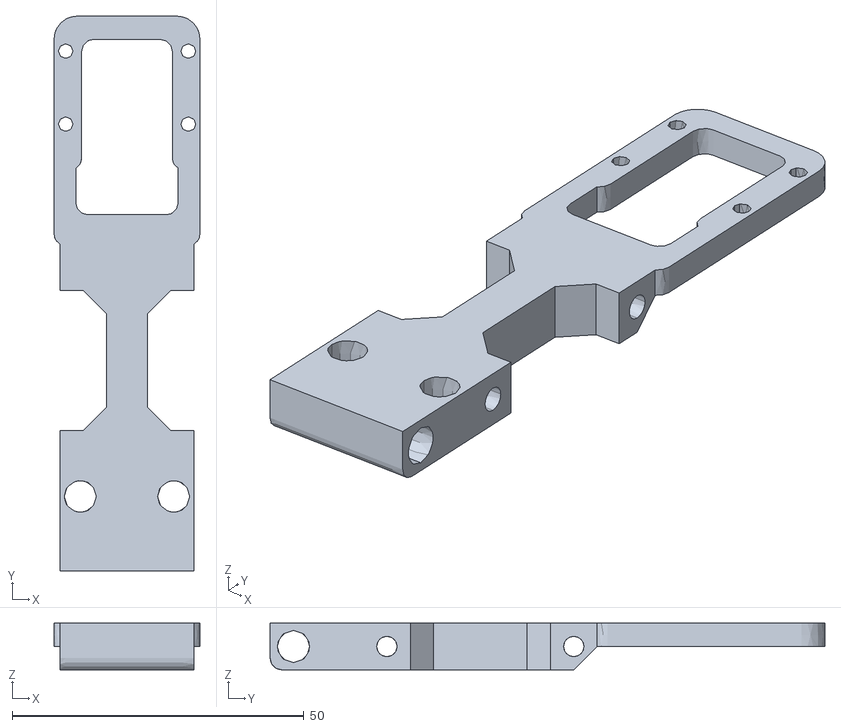
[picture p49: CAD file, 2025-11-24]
models/chassis/CameraMountArm.stl
25.0 x 95.0 x 8.00

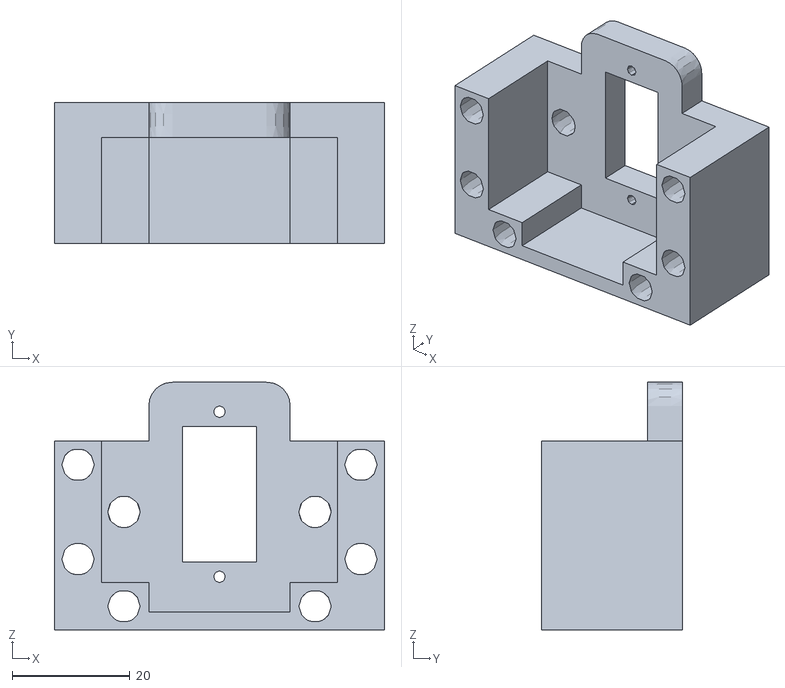
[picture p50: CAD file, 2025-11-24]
models/chassis/ServoMount3D.stl
56.0 x 24.0 x 42.0

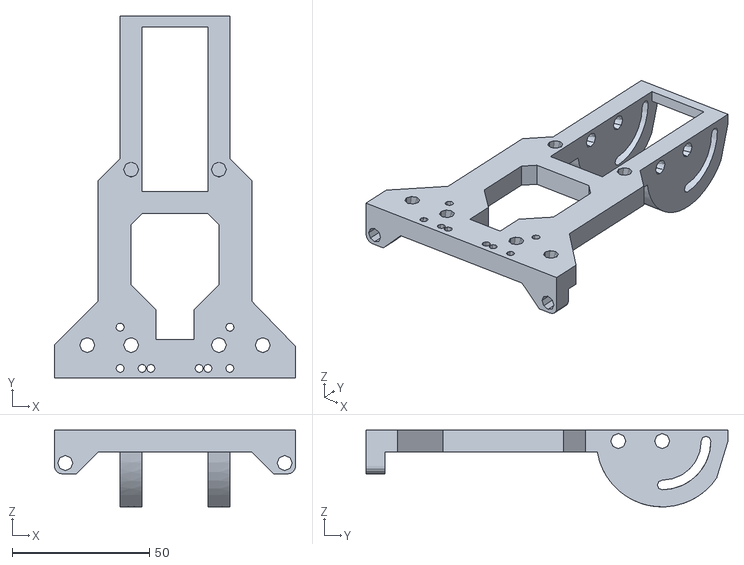
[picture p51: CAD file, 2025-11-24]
models/chassis/CameraMountBase.stl
88.0 x 132.0 x 28.0

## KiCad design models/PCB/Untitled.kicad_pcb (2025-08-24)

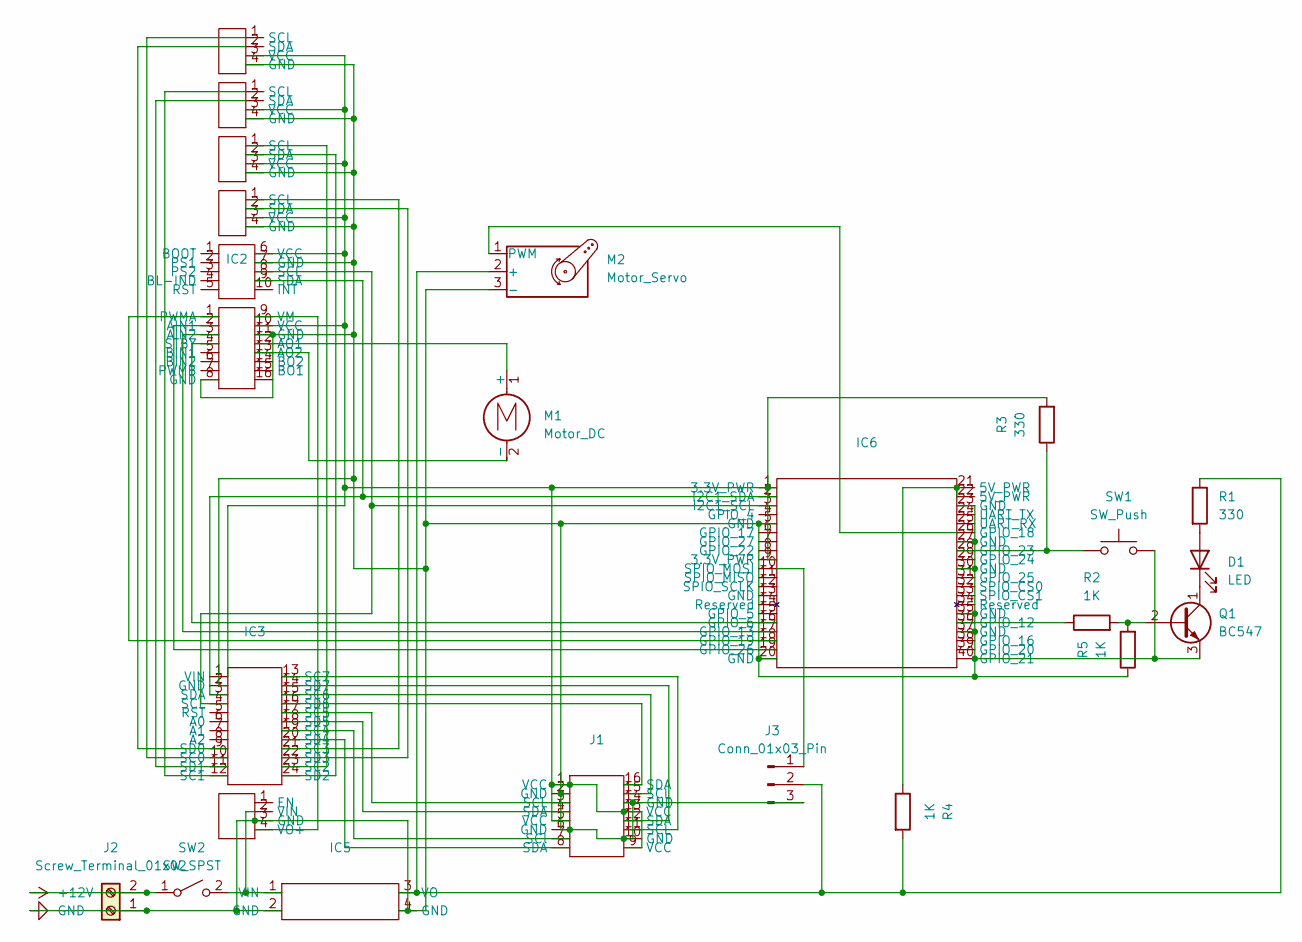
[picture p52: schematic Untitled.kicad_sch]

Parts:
D1: LED; LED_D5.0mm
IC1: DFRobot bno005 breakout board
IC2, IC3, IC6: Untitled
IC4: 12v to 9v buck converter
IC5: Untitled_1
J1: Untitled
J2: Screw_Terminal_01x02; TerminalBlock_bornier-2_P5.08mm
J3: Conn_01x03_Pin; PinHeader_1x03_P2.54mm_Vertical
M1: Motor_DC; PinHeader_1x02_P2.54mm_Vertical
M2: Motor_Servo; PinHeader_1x03_P2.54mm_Vertical
Q1: BC547; TO-92_Inline_Wide
R1, R3: 330; R_Axial_DIN0207_L6.3mm_D2.5mm_P10.16mm_Horizontal
R2, R4, R5: 1K; R_Axial_DIN0207_L6.3mm_D2.5mm_P10.16mm_Horizontal
SW1: SW_Push; SW_PUSH-12mm
SW2: SW_SPST; Untitled
U1, U2, U3, U4: VL53l1x; PinSocket_1x04_P2.54mm_Vertical

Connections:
+12V: J2.2, SW2.1 (A)
GND: IC1.7 (GND), IC2.8 (GND), IC2.11 (GND), IC3.2 (GND), IC4.3 (GND), IC5.2 (GND), IC5.4 (GND), IC6.5 (GND), IC6.20 (GND), IC6.23 (GND), IC6.27 (GND), IC6.30 (GND), IC6.35 (GND), IC6.37 (GND), J1.2 (GND), J1.6 (GND), J1.10 (GND), J1.14 (GND), J2.1, J3.3, M2.3 (-), Q1.3 (E), R5.1, SW1.2, U1.4 (GND), U2.4 (GND), U3.4 (GND), U4.4 (GND)
unnamed: D1.2 (A), R1.2
unnamed: D1.1 (K), Q1.1 (C)
unnamed: IC1.8 (SCL), IC3.4 (SCL), IC6.3 (I2C1_SCL)
unnamed: IC1.9 (SDA), IC3.3 (SDA), IC6.2 (I2C1_SDA)
unnamed: IC1.6 (VCC), IC2.10 (VCC), IC3.1 (VIN), IC6.1 (3.3V_PWR), IC6.9 (3.3V_PWR), J1.1 (VCC), J1.5 (VCC), J1.9 (VCC), J1.13 (VCC), R3.2, U1.3 (VCC), U2.3 (VCC), U3.3 (VCC), U4.3 (VCC)
unnamed: IC2.2 (AIN1), IC6.19 (GPIO_26)
unnamed: IC2.3 (AIN2), IC6.17 (GPIO_13)
unnamed: IC2.12 (AO1), M1.1 (+)
unnamed: IC2.13 (AO2), M1.2 (-)
unnamed: IC2.1 (PWMA), IC6.18 (GPIO_19)
unnamed: IC2.4 (STBY), IC6.16 (GPIO_6)
unnamed: IC2.9 (VM), IC4.4 (VO+)
unnamed: IC3.10 (SC0), U1.1 (SCL)
unnamed: IC3.12 (SC1), U2.1 (SCL)
unnamed: IC3.23 (SC2), U3.1 (SCL)
unnamed: IC3.21 (SC3), U4.1 (SCL)
unnamed: IC3.19 (SC4), J1.7 (SCl)
unnamed: IC3.17 (SC5), J1.3 (SCL)
unnamed: IC3.15 (SC6), J1.15 (SCL)
unnamed: IC3.13 (SC7), J1.11 (SCL)
unnamed: IC3.9 (SD0), U1.2 (SDA)
unnamed: IC3.11 (SD1), U2.2 (SDA)
unnamed: IC3.24 (SD2), U3.2 (SDA)
unnamed: IC3.22 (SD3), U4.2 (SDA)
unnamed: IC3.20 (SD4), J1.8 (SDA)
unnamed: IC3.18 (SD5), J1.4 (SDA)
unnamed: IC3.16 (SD6), J1.16 (SDA)
unnamed: IC3.14 (SD7), J1.12 (SDA)
unnamed: IC4.2 (VIN), IC5.1 (VIN), SW2.2 (B)
unnamed: IC5.3 (VO), J3.2, M2.2 (+), R1.1, R4.2
unnamed: IC6.21 (5V_PWR), IC6.22 (5V_PWR), R4.1
unnamed: IC6.36 (GPIO_12), R2.1
unnamed: IC6.26 (GPIO_18), M2.1 (PWM)
unnamed: IC6.28 (GPIO_23), R3.1, SW1.1
unnamed: IC6.10 (SPIO_MOSI), J3.1
unnamed: Q1.2 (B), R2.2, R5.2

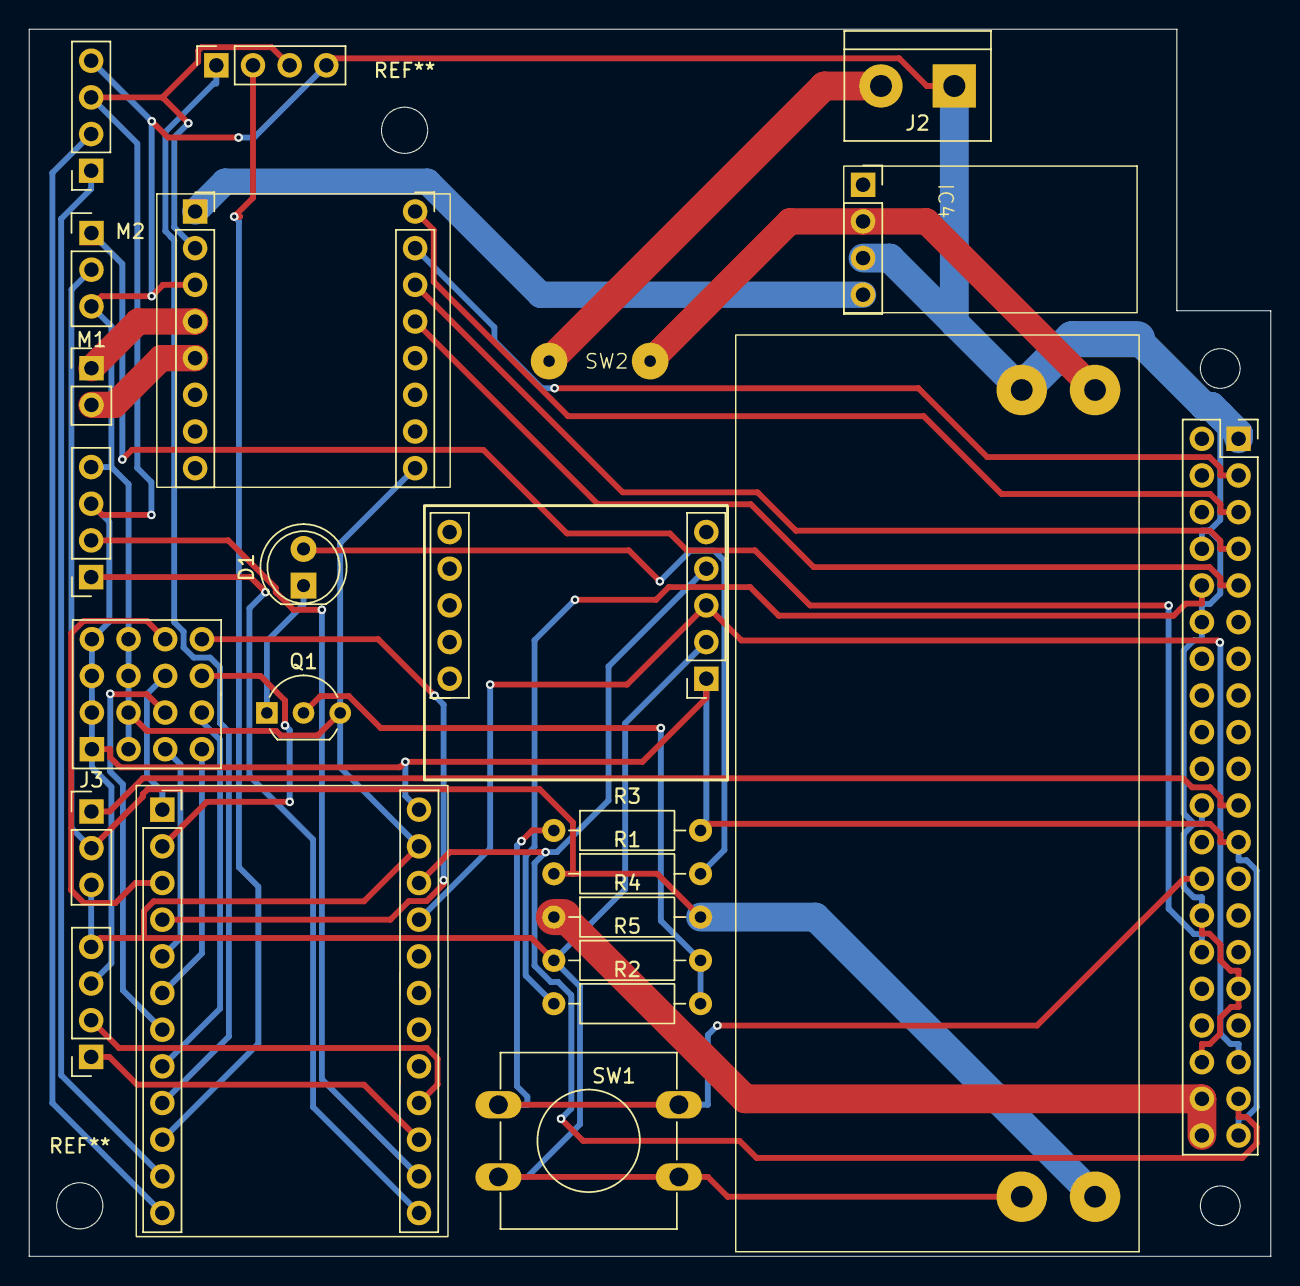
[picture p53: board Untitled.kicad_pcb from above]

Board: 2 copper layers, 86.0 x 85.0 mm, 24 parts (0 on the bottom side), 38 nets.

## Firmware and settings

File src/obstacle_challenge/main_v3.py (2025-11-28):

from collections import deque
import time
import queue
from src.sensors import bno055, camera, distance
from src.motors import motor, servo
import numpy as np
import cv2
import threading
from gpiozero import Button, LED
import os
import sys
import traceback
from datetime import datetime

# MOTOR_SPEED = 88
# ORANGE_COOLDOWN_FRAMES = 45

MOTOR_SPEED = 85
ORANGE_COOLDOWN_FRAMES = 50

#MOTOR_SPEED = 92
#ORANGE_COOLDOWN_FRAMES = 45

ORANGE_DETECTION_HISTORY_LENGTH = 4

WALL_THRESHOLD = 200

FRAME_WIDTH = 640
FRAME_HEIGHT = 360
FRAME_MIDPOINT_X = FRAME_WIDTH // 2

USE_LAB = False

HSV_RANGES = {
    'LOWER_RED_1': np.array([0, 100, 55]), 'UPPER_RED_1': np.array([5, 255, 255]),
    'LOWER_RED_2': np.array([174, 100, 55]), 'UPPER_RED_2': np.array([180, 255, 255]),
    'LOWER_GREEN': np.array([40, 108, 40]), 'UPPER_GREEN': np.array([80, 255, 180]),
    'LOWER_BLACK': np.array([0, 0, 0]), 'UPPER_BLACK': np.array([180, 95, 70]),
    'LOWER_ORANGE': np.array([6, 70, 20]), 'UPPER_ORANGE': np.array([26, 255, 255]),
    'LOWER_MAGENTA': np.array([158, 73, 64]), 'UPPER_MAGENTA': np.array([172, 255, 223]),
    'LOWER_BLUE': np.array([94, 45, 58]), 'UPPER_BLUE': np.array([140, 226, 185])
}

# Generic LAB values (OpenCV LAB: L=0-255, a=0-255, b=0-255)
LAB_RANGES = {
    'LOWER_RED_1': np.array([30, 159, 137]), 'UPPER_RED_1': np.array([158, 175, 169]),
    'LOWER_RED_2': np.array([20, 150, 150]), 'UPPER_RED_2': np.array([200, 255, 255]), # Duplicate for now
    'LOWER_GREEN': np.array([79, 80, 115]), 'UPPER_GREEN': np.array([134, 129, 146]),
    'LOWER_BLACK': np.array([0, 115, 115]), 'UPPER_BLACK': np.array([130, 134, 134]),
    'LOWER_ORANGE': np.array([97, 136, 138]), 'UPPER_ORANGE': np.array([177, 169, 172]),
    'LOWER_MAGENTA': np.array([72, 147, 48]), 'UPPER_MAGENTA': np.array([159, 174, 130]),
    'LOWER_BLUE': np.array([28, 136, 44]), 'UPPER_BLUE': np.array([100, 163, 104])
}

if USE_LAB:
    COLOR_RANGES = LAB_RANGES
else:
    COLOR_RANGES = HSV_RANGES

LOWER_RED_1 = COLOR_RANGES['LOWER_RED_1']
UPPER_RED_1 = COLOR_RANGES['UPPER_RED_1']
LOWER_RED_2 = COLOR_RANGES['LOWER_RED_2']
UPPER_RED_2 = COLOR_RANGES['UPPER_RED_2']
LOWER_GREEN = COLOR_RANGES['LOWER_GREEN']
UPPER_GREEN = COLOR_RANGES['UPPER_GREEN']
LOWER_BLACK = COLOR_RANGES['LOWER_BLACK']
UPPER_BLACK = COLOR_RANGES['UPPER_BLACK']
LOWER_ORANGE = COLOR_RANGES['LOWER_ORANGE']
UPPER_ORANGE = COLOR_RANGES['UPPER_ORANGE']
LOWER_MAGENTA = COLOR_RANGES['LOWER_MAGENTA']
UPPER_MAGENTA = COLOR_RANGES['UPPER_MAGENTA']
LOWER_BLUE = COLOR_RANGES['LOWER_BLUE']
UPPER_BLUE = COLOR_RANGES['UPPER_BLUE']
target=0
detection_params = {'min_area': 300, 'return_rule': 'biggest_in_job', 'return_mask': True}
WALL_MIN_AREA = detection_params['min_area']
BLOCK_MIN_AREA = 500
MAGENTA_MIN_AREA = 500
CLOSE_BLOCK_MIN_AREA = 15

left_roi_x, left_roi_y, left_roi_w, left_roi_h = 0, 140, 135, 150
right_roi_x, right_roi_y, right_roi_w, right_roi_h = 505, 140, 135, 150
inner_left_roi_x, inner_left_roi_y, inner_left_roi_w, inner_left_roi_h = 140, 165, 100, 100
inner_right_roi_x, inner_right_roi_y, inner_right_roi_w, inner_right_roi_h = 400, 165 , 100, 100
line_roi_x, line_roi_y, line_roi_w, line_roi_h = 280, 200, 80, 40
close_x,close_y,close_w,close_h = 140,120,360,10
full_frame_roi = (0, 100, 640, 165)
close_block_roi = (250, 230, 140, 10)

left_side_job = {'roi': (left_roi_x, left_roi_y, left_roi_w, left_roi_h), 'type': 'wall_left'}
right_side_job = {'roi': (right_roi_x, right_roi_y, right_roi_w, right_roi_h), 'type': 'wall_right'}
inner_left_side_job = {'roi': (inner_left_roi_x, inner_left_roi_y, inner_left_roi_w, inner_left_roi_h), 'type': 'wall_inner_left'}
inner_right_side_job = {'roi': (inner_right_roi_x, inner_right_roi_y, inner_right_roi_w, inner_right_roi_h), 'type': 'wall_inner_right'}

roi_mask_walls = np.zeros((FRAME_HEIGHT, FRAME_WIDTH), dtype="uint8")
for job in [left_side_job, right_side_job, inner_left_side_job, inner_right_side_job]:
    x, y, w, h = job['roi']
    cv2.rectangle(roi_mask_walls, (x, y), (x + w, y + h), 255, -1)

roi_mask_main_blocks = np.zeros((FRAME_HEIGHT, FRAME_WIDTH), dtype="uint8")
x, y, w, h = full_frame_roi
cv2.rectangle(roi_mask_main_blocks, (x, y), (x + w, y + h), 255, -1)

roi_mask_close_blocks = np.zeros((FRAME_HEIGHT, FRAME_WIDTH), dtype="uint8")
x, y, w, h = close_block_roi
cv2.rectangle(roi_mask_close_blocks, (x, y), (x + w, y + h), 255, -1)

roi_mask_line = np.zeros((FRAME_HEIGHT, FRAME_WIDTH), dtype="uint8")
cv2.rectangle(roi_mask_line, (line_roi_x, line_roi_y), (line_roi_x + line_roi_w, line_roi_h + line_roi_y), 255, -1)

roi_mask_magenta = np.zeros((FRAME_HEIGHT, FRAME_WIDTH), dtype="uint8")
x, y, w, h = full_frame_roi
cv2.rectangle(roi_mask_magenta, (x, y), (x + w, y + h), 255, -1)

roi_mask_close_black = np.zeros((FRAME_HEIGHT, FRAME_WIDTH), dtype="uint8")
cv2.rectangle(roi_mask_close_black, (close_x, close_y), (close_x + close_w, close_y + close_h), 255, -1)

class CameraThread(threading.Thread):
    def __init__(self, camera_instance):
        super().__init__()
        self.camera = camera_instance
        self.latest_frame = None
        self.lock = threading.Lock()
        self.stop_event = threading.Event()
        self.daemon = True
        self.frame_counter = 0

    def run(self):
        while not self.stop_event.is_set():
            frame = self.camera.capture_frame()
            with self.lock:
                self.frame_counter += 1
                self.latest_frame = frame

    def get_frame(self):
        with self.lock:
            if self.latest_frame is not None:
                return self.latest_frame.copy(), self.frame_counter
            return None

    def stop(self):
        self.stop_event.set()

class ImuThread(threading.Thread):
    def __init__(self, bno, init_event):
        super().__init__()
        self.bno = bno
        self.initialization_complete = init_event
        self.lock = threading.Lock()
        self.stop_event = threading.Event()
        self.daemon = True
        self.heading = None

    def run(self):
        try:
            self.bno.initialize()
            print("ImuThread: IMU initialized.")
            self.initialization_complete.set()
            while not self.stop_event.is_set():
                heading = self.bno.get_heading()
                with self.lock:
                    self.heading = heading
        except Exception as e:
            print(f"ImuThread: ERROR during initialization/operation: {e}")
            traceback.print_exc()
            self.initialization_complete.set()
        finally:
            self.bno.cleanup()
            print("ImuThread: IMU cleanup complete.")

    def get_heading(self):
        with self.lock:
            return self.heading

    def stop(self):
        self.stop_event.set()

class VideoWriterThread(threading.Thread):
    def __init__(self, path, fourcc, fps, frame_size):
        super().__init__()
        self.out = cv2.VideoWriter(path, fourcc, fps, frame_size)
        self.queue = queue.Queue()
        self.stop_event = threading.Event()
        self.daemon = True

    def run(self):
        while not self.stop_event.is_set() or not self.queue.empty():
            try:
                frame = self.queue.get(timeout=0.1)
                self.out.write(frame)
                self.queue.task_done()
            except queue.Empty:
                continue
            except:
                print(f"VideoWriterThread: ERROR writing frame")
                traceback.print_exc()
                continue
        self.out.release()

    def write(self, frame):
        if not self.stop_event.is_set():
            self.queue.put(frame)

    def stop(self):
        self.stop_event.set()

class SensorThread(threading.Thread):
    def __init__(self, dist, init_event):
        super().__init__()
        self.dist = dist
        self.initialization_complete = init_event
        self.lock = threading.Lock()
        self.stop_event = threading.Event()
        self.daemon = True
        self.distance_left = None
        self.distance_right = None
        self.distance_back = None
        self.distance_center = None

    def run(self):
        try:
            for attempt in range(3):
                try:
                    print("SensorThread: Initializing distance sensors...")
                    self.dist.initialise()
                    print("SensorThread: Both sensors initialized.")
                    break
                except Exception as e:
                    print(f"SensorThread: ERROR during initialization: {e}")
                    traceback.print_exc()
                time.sleep(0.3)
            time.sleep(0.3)
            print("SensorThread: Initialization complete flag set.")
            self.initialization_complete.set()

            consecutive_none = {ch: 0 for ch in [-1, 0, 2, 3]}
            reinit_threshold = 30
            while not self.stop_event.is_set():
                try:
                    readings = {}
                    for ch in list(consecutive_none.keys()):
                        val = self.dist.get_distance(ch)
                        if ch == -1:
                            print(f"DEBUG: SensorThread get_distance({ch}) -> {val}")
                        readings[ch] = val
                        if val is None:
                            consecutive_none[ch] = consecutive_none.get(ch, 0) + 1
                        else:
                            consecutive_none[ch] = 0

                    with self.lock:
                        self.distance_left = readings.get(0)
                        self.distance_center = readings.get(2)
                        self.distance_right = readings.get(3)
                        self.distance_back = readings.get(-1)

                    for ch, count in list(consecutive_none.items()):
                        if count >= reinit_threshold:
                            #ok = distance.reinit_sensor(ch)
                            #print(f"DEBUG: Re-init returned: {ok}")
                            #consecutive_none[ch] = 0 if ok else count
                            pass

                    time.sleep(0.02) # account for timing budget 
                except Exception as e:
                    print(f"SensorThread: ERROR during sensor reading: {e}")
                    traceback.print_exc()
                    time.sleep(0.1)
        
        except Exception as e:
            print(f"SensorThread: ERROR during initialization/operation: {e}")
            traceback.print_exc()
            # Still set the event so main thread doesn't hang forever
            self.initialization_complete.set()
        
        finally:
            print("SensorThread: Cleaning up distance sensors...")
            self.dist.cleanup()
            print("SensorThread: Distance sensor cleanup complete.")

    def get_readings(self):
        with self.lock:
            return {
                'distance_left': self.distance_left,
                'distance_center': self.distance_center,
                'distance_right': self.distance_right,
                'distance_back' : self.distance_back
            }

    def stop(self):
        self.stop_event.set()

def get_angular_difference(angle1, angle2):
    if angle1 is None or angle2 is None:
        return 360
    diff = angle1 - angle2
    while diff <= -180:
        diff += 360
    while diff > 180:
        diff -= 360
    return abs(diff)

def process_video_frame(frame):
    processed_data = {
        'detected_blocks': [],
        'detected_walls': [],
        'detected_orange': [],
        'detected_blue' : [],
        'detected_magenta': [],
        'detected_close_black': []
    }
    
    # frame = cv2.GaussianBlur(frame,(1,7),0) # Commented out in original? No, it was active.
    # Global Slicing Constants
    GLOBAL_Y_OFFSET = 100
    GLOBAL_Y_END = 290
    SLICE_HEIGHT = GLOBAL_Y_END - GLOBAL_Y_OFFSET

    # Slice the frame first
    frame_slice = frame[GLOBAL_Y_OFFSET:GLOBAL_Y_END, :]
    frame_slice = cv2.GaussianBlur(frame_slice, (1, 7), 0)
    
    if USE_LAB:
        hsv_slice = cv2.cvtColor(frame_slice, cv2.COLOR_BGR2Lab)
    else:
        hsv_slice = cv2.cvtColor(frame_slice, cv2.COLOR_BGR2HSV)

    # --- 1. Crop and Detect (Relative to Slice) ---

    # Main Blocks ROI (Red, Green, Magenta)
    # full_frame_roi = (0, 100, 640, 165) -> y=100 in global is y=0 in slice
    mx, my, mw, mh = full_frame_roi
    my_slice = my - GLOBAL_Y_OFFSET
    # Ensure we don't go out of bounds
    my_slice = max(0, my_slice)
    
    main_crop = hsv_slice[my_slice:my_slice+mh, mx:mx+mw]
    
    mask_red1_main = cv2.inRange(main_crop, LOWER_RED_1, UPPER_RED_1)
    if USE_LAB:
        # In LAB, Red is continuous, so we only need one mask
        mask_red_main = mask_red1_main
    else:
        # In HSV, Red wraps around 180->0, so we need two masks combined
        mask_red2_main = cv2.inRange(main_crop, LOWER_RED_2, UPPER_RED_2)
        mask_red_main = cv2.bitwise_or(mask_red1_main, mask_red2_main)
    mask_green_main = cv2.inRange(main_crop, LOWER_GREEN, UPPER_GREEN)
    mask_magenta_main = cv2.inRange(main_crop, LOWER_MAGENTA, UPPER_MAGENTA)

    # Line ROI (Orange, Blue)
    # line_roi_y = 200 -> y=200 in global is y=100 in slice
    lx, ly, lw, lh = line_roi_x, line_roi_y, line_roi_w, line_roi_h
    ly_slice = ly - GLOBAL_Y_OFFSET
    
    line_crop = hsv_slice[ly_slice:ly_slice+lh, lx:lx+lw]
    
    mask_orange_line = cv2.inRange(line_crop, LOWER_ORANGE, UPPER_ORANGE)
    mask_blue_line = cv2.inRange(line_crop, LOWER_BLUE, UPPER_BLUE)

    # Close Blocks ROI (Red, Green, Magenta)
    # close_block_roi = (250, 230, 140, 10) -> y=230 in global is y=130 in slice
    cx, cy, cw, ch = close_block_roi
    cy_slice = cy - GLOBAL_Y_OFFSET
    
    close_crop = hsv_slice[cy_slice:cy_slice+ch, cx:cx+cw]
    
    mask_red1_close = cv2.inRange(close_crop, LOWER_RED_1, UPPER_RED_1)
    
    if USE_LAB:
        mask_red_close = mask_red1_close
    else:
        mask_red2_close = cv2.inRange(close_crop, LOWER_RED_2, UPPER_RED_2)
        mask_red_close = cv2.bitwise_or(mask_red1_close, mask_red2_close)

    mask_green_close = cv2.inRange(close_crop, LOWER_GREEN, UPPER_GREEN)
    mask_magenta_close = cv2.inRange(close_crop, LOWER_MAGENTA, UPPER_MAGENTA)

    # Close Black ROI
    # close_y = 120 -> y=120 in global is y=20 in slice
    cbx, cby, cbw, cbh = close_x, close_y, close_w, close_h
    cby_slice = cby - GLOBAL_Y_OFFSET

    # --- 2. Reconstruct Global Masks (Slice Size) for Wall/Black Detection ---
    
    global_red_mask = np.zeros((SLICE_HEIGHT, FRAME_WIDTH), dtype="uint8")
    global_green_mask = np.zeros((SLICE_HEIGHT, FRAME_WIDTH), dtype="uint8")
    global_blue_mask = np.zeros((SLICE_HEIGHT, FRAME_WIDTH), dtype="uint8")
    global_magenta_mask = np.zeros((SLICE_HEIGHT, FRAME_WIDTH), dtype="uint8")

    # Paste Main Blocks
    global_red_mask[my_slice:my_slice+mh, mx:mx+mw] = cv2.bitwise_or(global_red_mask[my_slice:my_slice+mh, mx:mx+mw], mask_red_main)
    global_green_mask[my_slice:my_slice+mh, mx:mx+mw] = cv2.bitwise_or(global_green_mask[my_slice:my_slice+mh, mx:mx+mw], mask_green_main)
    global_magenta_mask[my_slice:my_slice+mh, mx:mx+mw] = cv2.bitwise_or(global_magenta_mask[my_slice:my_slice+mh, mx:mx+mw], mask_magenta_main)

    # Paste Close Blocks
    global_red_mask[cy_slice:cy_slice+ch, cx:cx+cw] = cv2.bitwise_or(global_red_mask[cy_slice:cy_slice+ch, cx:cx+cw], mask_red_close)
    global_green_mask[cy_slice:cy_slice+ch, cx:cx+cw] = cv2.bitwise_or(global_green_mask[cy_slice:cy_slice+ch, cx:cx+cw], mask_green_close)
    global_magenta_mask[cy_slice:cy_slice+ch, cx:cx+cw] = cv2.bitwise_or(global_magenta_mask[cy_slice:cy_slice+ch, cx:cx+cw], mask_magenta_close)

    # Paste Line Blocks (Blue)
    global_blue_mask[ly_slice:ly_slice+lh, lx:lx+lw] = cv2.bitwise_or(global_blue_mask[ly_slice:ly_slice+lh, lx:lx+lw], mask_blue_line)

    # --- 3. Wall and Black Detection ---
    
    mask_black = cv2.inRange(hsv_slice, LOWER_BLACK, UPPER_BLACK)
    
    mask_red_or_green = cv2.bitwise_or(global_red_mask, global_green_mask)
    mask_red_or_green_or_blue = cv2.bitwise_or(mask_red_or_green, global_blue_mask)
    
    pure_black_mask = cv2.bitwise_and(mask_black, cv2.bitwise_not(mask_red_or_green_or_blue))
    black_or_magenta_mask = cv2.bitwise_or(pure_black_mask, global_magenta_mask)

    # Sliced ROI Masks
    roi_mask_walls_slice = roi_mask_walls[GLOBAL_Y_OFFSET:GLOBAL_Y_END, :]
    roi_mask_close_black_slice = roi_mask_close_black[GLOBAL_Y_OFFSET:GLOBAL_Y_END, :]

    final_mask_walls = cv2.bitwise_and(pure_black_mask, roi_mask_walls_slice)
    final_mask_close_black = cv2.bitwise_and(black_or_magenta_mask, roi_mask_close_black_slice)

    # --- 4. Contour Finding (Fast-Fail) ---

    # Magenta (Main)
    # We already have mask_magenta_main from the crop.
    # But original code used final_mask_magenta = bitwise_and(mask_magenta, roi_mask_magenta)
    # roi_mask_magenta was full_frame_roi. So mask_magenta_main IS the correct mask.
    
    if cv2.countNonZero(mask_magenta_main) > 0:
        contours, _ = cv2.findContours(mask_magenta_main, cv2.RETR_EXTERNAL, cv2.CHAIN_APPROX_SIMPLE)
        if contours:
            biggest_contour = max(contours, key=cv2.contourArea)
            area = cv2.contourArea(biggest_contour)

            if area > MAGENTA_MIN_AREA:
                M = cv2.moments(biggest_contour)
                if M["m00"] != 0:
                    # Correct coordinates
                    # cx is relative to crop, so add mx (which is relative to slice? No, mx is absolute X)
                    # cy is relative to crop, so add my_slice (relative to slice) + GLOBAL_Y_OFFSET (absolute)
                    # Actually, my is absolute Y. So my_slice + GLOBAL_Y_OFFSET = my.
                    # So we can just add mx and my.
                    cx = int(M["m10"] / M["m00"]) + mx
                    cy = int(M["m01"] / M["m00"]) + my

                    # Correct contour for drawing/display if needed
                    biggest_contour_global = biggest_contour + [mx, my]

                    leftmost_x = biggest_contour_global[:, 0, 0].min()
                    rightmost_x = biggest_contour_global[:, 0, 0].max()

                    dist_to_center_left = abs(leftmost_x - FRAME_MIDPOINT_X)
                    dist_to_center_right = abs(rightmost_x - FRAME_MIDPOINT_X)

                    if dist_to_center_left <= dist_to_center_right:
                        target_x = leftmost_x
                    else:
                        target_x = rightmost_x
                    
                    processed_data['detected_magenta'].append({
                        'type': 'magenta_block',
                        'area': area,
                        'centroid': (cx, cy),
                        'contour': biggest_contour_global,
                        'target_x': target_x,
                        'target_y': cy
                    })

    # Blocks (Red, Green, Magenta - Main & Close)
    
    # Helper function to process block contours
    def process_block_contours(mask, offset_x, offset_y, b_type, b_color, min_area):
        if cv2.countNonZero(mask) > 0:
            contours, _ = cv2.findContours(mask, cv2.RETR_EXTERNAL, cv2.CHAIN_APPROX_SIMPLE)
            if contours:
                biggest_contour = max(contours, key=cv2.contourArea)
                area = cv2.contourArea(biggest_contour)
                if area > min_area:
                    M = cv2.moments(biggest_contour)
                    if M["m00"] != 0:
                        cx = int(M["m10"] / M["m00"]) + offset_x
                        cy = int(M["m01"] / M["m00"]) + offset_y
                        biggest_contour_global = biggest_contour + [offset_x, offset_y]
                        return {'type': b_type, 'color': b_color, 'area': area, 'centroid': (cx, cy), 'contour': biggest_contour_global}
        return None

    all_detected_blocks = []
    
    # Main Red
    res = process_block_contours(mask_red_main, mx, my, 'block', 'red', BLOCK_MIN_AREA)
    if res: all_detected_blocks.append(res)
    
    # Main Green
    res = process_block_contours(mask_green_main, mx, my, 'block', 'green', BLOCK_MIN_AREA)
    if res: all_detected_blocks.append(res)

    # Close Red
    res = process_block_contours(mask_red_close, cx, cy, 'close_block', 'red', CLOSE_BLOCK_MIN_AREA)
    if res: all_detected_blocks.append(res)

    # Close Green
    res = process_block_contours(mask_green_close, cx, cy, 'close_block', 'green', CLOSE_BLOCK_MIN_AREA)
    if res: all_detected_blocks.append(res)

    # Close Magenta
    res = process_block_contours(mask_magenta_close, cx, cy, 'close_block', 'magenta', CLOSE_BLOCK_MIN_AREA)
    if res: all_detected_blocks.append(res)

    main_blocks = [b for b in all_detected_blocks if b['type'] == 'block']
    other_blocks = [b for b in all_detected_blocks if b['type'] != 'block']
    if len(main_blocks) > 1:
        lowest_main_block = max(main_blocks, key=lambda b: b['centroid'][1])
        main_blocks = [lowest_main_block]
    processed_data['detected_blocks'] = main_blocks + other_blocks
    
    # Orange (Line)
    if cv2.countNonZero(mask_orange_line) > 0:
        contours, _ = cv2.findContours(mask_orange_line, cv2.RETR_EXTERNAL, cv2.CHAIN_APPROX_SIMPLE)
        if contours:
            biggest_contour = max(contours, key=cv2.contourArea)
            area = cv2.contourArea(biggest_contour)
            if area > 20:
                M = cv2.moments(biggest_contour)
                if M["m00"] != 0:
                    cx = int(M["m10"] / M["m00"]) + lx
                    cy = int(M["m01"] / M["m00"]) + ly
                    biggest_contour_global = biggest_contour + [lx, ly]
                    processed_data['detected_orange'].append({'type': 'orange_block', 'color': 'orange', 'area': area, 'centroid': (cx, cy), 'contour': biggest_contour_global})
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

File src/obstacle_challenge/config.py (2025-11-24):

import numpy as np


TILT_THRESHOLD_DEGREES = 15.0


DRIVE_SPEED = 100.0


FRAME_WIDTH = 640
FRAME_HEIGHT = 480
MAX_FPS = 30
CROP_TOP_FRAC = 0
CROP_BOTTOM_FRAC = 0
MIN_CONTOUR_AREA = 2500
MAX_BLOCK_AREA_FRACTION = 0.25
MIN_BLOCK_ROI_OVERLAP = 0.50


MIN_BLOCK_AREA_FOR_ACTION = 7500
MANEUVER_ANGLE_DEG = 45.0
MIN_FRAMES_IN_TURN = 30
TOTAL_TURNS = 12
MANEUVER_DRIVE_FRAMES_SIDEWAYS = 10
MANEUVER_DRIVE_FRAMES_STRAIGHT = 0
SPECIAL_TURN_SIDEWAYS_FRAMES = 0


CCW_TURN_ANGLE = 90.0
CCW_SCAN_ANGLE = 60.0
CCW_NORMAL_DRIVE_FRAMES = 25
CCW_REVERSE_FRAMES = 10
CCW_SHORT_DRIVE_FRAMES = 0


CW_DRIVE_FORWARD_RED_FRAMES = 25
CW_REVERSE_GREEN_FRAMES = 15
CW_DRIVE_FORWARD_NONE_FRAMES = 0

GYRO_ENABLED = True
GYRO_KP = 3.0
HEADING_LOCK_TOLERANCE = 5.0

TOF_ENABLED = True
TOF_CHANNELS_TO_USE = range(1,4)
TOF_FORWARD_SENSOR_CHANNEL = 1
TOF_CORNERING_THRESHOLD_MM = 240
TOF_OBSTACLE_THRESHOLD_MM = 100
WALL_FOLLOW_KP = 0.2


AIN1_PIN = 26
AIN2_PIN = 13
STBY_PIN = 6
MOTOR_PWM_PIN = 19
MOTOR_PWM_FREQ = 10000
MOTOR_PWM_CHIP = 0
MOTOR_PWM_CHANNEL = 3
SERVO_GPIO = 18
SERVO_PWM_FREQ = 50
SERVO_PWM_CHIP = 0
SERVO_PWM_CHANNEL = 2
CALIBRATED_MIN_PW_S = 0.001
CALIBRATED_MAX_PW_S = 0.002
CALIBRATED_ANGLE_MIN = 45.0
CALIBRATED_ANGLE_MAX = 135.0
INPUT_ANGLE_MIN_SERVO = -45.0
INPUT_ANGLE_MAX_SERVO = 45.0
SAFETY_MIN_PW_S = 0.001
SAFETY_MAX_PW_S = 0.0021
SERVO_PWM_PERIOD_S = 1.0 / SERVO_PWM_FREQ


BOX_COLOR_RED = (0, 0, 255)
BOX_COLOR_GREEN = (0, 255, 0)
BOX_COLOR_ROI = (255, 0, 255)

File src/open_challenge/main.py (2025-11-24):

from collections import deque
import time
import threading
import cv2
import numpy as np
from gpiozero import Button, LED
import os
import sys
import traceback
from datetime import datetime

# Import all settings from the new config file
from src.obstacle_challenge.main_v3 import get_angular_difference
import src.open_challenge.config as config

# Import hardware control modules
from src.sensors import bno055, camera, distance
from src.motors import motor, servo

ORANGE_COOLDOWN_FRAMES = 50
ORANGE_DETECTION_HISTORY_LENGTH = 4

class CameraThread(threading.Thread):
    def __init__(self, camera_instance):
        super().__init__()
        self.camera = camera_instance
        self.latest_frame = None
        self.lock = threading.Lock()
        self.stop_event = threading.Event()
        self.daemon = True

    def run(self):
        while not self.stop_event.is_set():
            frame = self.camera.capture_frame()
            with self.lock:
                self.latest_frame = frame

    def get_frame(self):
        with self.lock:
            if self.latest_frame is not None:
                return self.latest_frame.copy()
            return None

    def stop(self):
        self.stop_event.set()

class ImuThread(threading.Thread):
    def __init__(self, bno, init_event):
        super().__init__()
        self.bno = bno
        self.initialization_complete = init_event
        self.lock = threading.Lock()
        self.stop_event = threading.Event()
        self.daemon = True
        self.heading = None

    def run(self):
        try:
            self.bno.initialize()
            print("ImuThread: IMU initialized.")
            self.initialization_complete.set()
            while not self.stop_event.is_set():
                heading = self.bno.get_heading()
                with self.lock:
                    self.heading = heading
        except Exception as e:
            print(f"ImuThread: ERROR during initialization/operation: {e}")
            traceback.print_exc()
            self.initialization_complete.set()
        finally:
            self.bno.cleanup()
            print("ImuThread: IMU cleanup complete.")

    def get_heading(self):
        with self.lock:
            return self.heading

    def stop(self):
        self.stop_event.set()


def process_video_frame(frame):
    processed_data = {
        'detected_walls': [],
        'detected_orange': [],
        'detected_close_black': []
    }
    
    frame = cv2.GaussianBlur(frame,(1,7),0)
    hsv_frame = cv2.cvtColor(frame, cv2.COLOR_BGR2HSV)

    mask_black = cv2.inRange(hsv_frame, config.LOWER_BLACK, config.UPPER_BLACK)
    mask_orange = cv2.inRange(hsv_frame, config.LOWER_ORANGE, config.UPPER_ORANGE)

    # Apply ROI masks to get detections only in the desired areas
    final_mask_walls = cv2.bitwise_and(mask_black, config.roi_mask_walls)
    final_mask_orange = cv2.bitwise_and(mask_orange, config.roi_mask_orange)
    final_mask_close_black = cv2.bitwise_and(mask_black, config.roi_mask_close_black)

    # Detect orange line for turn counting
    contours, _ = cv2.findContours(final_mask_orange, cv2.RETR_EXTERNAL, cv2.CHAIN_APPROX_SIMPLE)
    if contours:
        biggest_contour = max(contours, key=cv2.contourArea)
        area = cv2.contourArea(biggest_contour)
        if area > config.ORANGE_MIN_AREA:
            M = cv2.moments(biggest_contour)
            if M["m00"] != 0:
                cx = int(M["m10"] / M["m00"])
                cy = int(M["m01"] / M["m00"])
                processed_data['detected_orange'].append({'area': area, 'centroid': (cx, cy)})

    # Detect "close black" walls for sharp turn avoidance
    contours, _ = cv2.findContours(final_mask_close_black, cv2.RETR_EXTERNAL, cv2.CHAIN_APPROX_SIMPLE)
    for contour in contours:
        area = cv2.contourArea(contour)
        if area > config.WALL_MIN_AREA:
            processed_data['detected_close_black'].append({'area': area})

    # Detect side walls for steering
    wall_contours_by_roi = {job['type']: [] for job in [config.left_side_job, config.right_side_job, config.inner_left_side_job, config.inner_right_side_job]}
    contours, _ = cv2.findContours(final_mask_walls, cv2.RETR_EXTERNAL, cv2.CHAIN_APPROX_SIMPLE)
    for c in contours:
        if cv2.contourArea(c) > config.WALL_MIN_AREA:
            M = cv2.moments(c)
            if M["m00"] == 0: continue
            cx = int(M["m10"] / M["m00"])

            # Determine which ROI the contour belongs to
            job_type = 'unknown'
            if config.left_side_job['roi'][0] <= cx < config.left_side_job['roi'][0] + config.left_side_job['roi'][2]: job_type = config.left_side_job['type']
            elif config.right_side_job['roi'][0] <= cx < config.right_side_job['roi'][0] + config.right_side_job['roi'][2]: job_type = config.right_side_job['type']
            elif config.inner_left_side_job['roi'][0] <= cx < config.inner_left_side_job['roi'][0] + config.inner_left_side_job['roi'][2]: job_type = config.inner_left_side_job['type']
            elif config.inner_right_side_job['roi'][0] <= cx < config.inner_right_side_job['roi'][0] + config.inner_right_side_job['roi'][2]: job_type = config.inner_right_side_job['type']

            if job_type != 'unknown':
                wall_contours_by_roi[job_type].append(c)

    # Find the biggest contour in each ROI and add it to the processed data
    for job_type, contour_list in wall_contours_by_roi.items():
        if contour_list:
            biggest_contour = max(contour_list, key=cv2.contourArea)
            area = cv2.contourArea(biggest_contour)
            processed_data['detected_walls'].append({'type': job_type, 'area': area, 'contour': biggest_contour})
    
    return processed_data

def annotate_video_frame(frame, detections, debug_info=""):
    annotated_frame = frame.copy()
    light_blue = (255, 255, 0)

    # Define all ROIs for drawing
    all_rois = [
        config.left_side_job['roi'], config.right_side_job['roi'],
        config.inner_left_side_job['roi'], config.inner_right_side_job['roi'],
        (config.orange_roi_x, config.orange_roi_y, config.orange_roi_w, config.orange_roi_h),
        (config.close_x, config.close_y, config.close_w, config.close_h),
    ]
    # Draw ROIs on the frame
    for x, y, w, h in all_rois:
        cv2.rectangle(annotated_frame, (x, y), (x + w, y + h), light_blue, 2)

    # Draw detected walls
    for wall in detections['detected_walls']:
        cv2.drawContours(annotated_frame, [wall['contour']], -1, (255, 0, 0), 2)

    # Draw detected orange line
    if detections['detected_orange']:
        cv2.circle(annotated_frame, detections['detected_orange'][0]['centroid'], 5, (0, 165, 255), -1)

    # Add debug text to the frame
    cv2.putText(annotated_frame, str(debug_info), (10, 30), cv2.FONT_HERSHEY_SIMPLEX, 0.7, (255, 255, 255), 2, cv2.LINE_AA)
    
    return annotated_frame
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

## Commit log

2025-07-19 19/07 Photos
    Rubber Banded Distance Sensor and Camera Hot Glues
2025-08-02 Upgraded sensor to vl53l1x, and fixed open_challenge. Added a stop function which stops the robot when tilted for easy stopping.
    [camera.py, config.py, main.py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]
2025-08-09 Tuned obstacle challenge, does 3 round, no parking. added logic to open challenge to wall follow in start if too close
    [camera.py, config.py, main.py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]
2025-08-24 Power and Sense, Mobility, and obstacle completed
    [ServoMount3D.stl, Untitled.kicad_pcb, Untitled.kicad_sch]
2025-08-28 Team photos added
    [Untitled.kicad_sch]
2025-08-31 sunday night 9pm, parking works, obstacle works. added gyro callibration routine, made changes to button press starting up routine.
2025-09-02 monday night tuning, issue in red cv. headles added, fixed gyro drift.
    [config.py, main.py]
2025-09-02 tuesday night, issues in red cv and parking. tested headless.
    [config.py, main.py]
2025-09-02 Wiring Diagram Updated
2025-09-02 Wiring Diagram Size Change
2025-10-25 Major changes to how robot works, primarily using only camera. still in testing phase, src/obstacle_challenge/test2.py contains most of this code
2025-10-29 Tuned for camera module 3, works well. To implment VL53L8CX and parking avoidance and parllel parking
    [camera.py, config.py, distance.py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]
2025-10-30 added logic to avoid hitting parking
    [main.py, test3.py]
2025-11-02 added vl53l8cx support for back sensor, 3d printed lots of parts of tuned robot
2025-11-06 Made distance functions non blocking and fine tuned parking logic to work reliably in one direction, primarily using camera
2025-11-11 fixed issue where robot crashes into parking, made open challenge code
    [config.py, main.py, servo.py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]
2025-11-14 working for most part, magenta avoidance to be tuned
    [config.py, test2.py, test3.py]
2025-11-19 changed servo back to sg90 as mg90 burnt. Tuned for sg90 and optimized parking manuver
    [config.py, servo.py, test3.py]
2025-11-20 Tuned parking in multiple scenarios and added timeout in certain parking parts to ensure robot is not stuck
    [config.py, main.py, test2.py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]
2025-11-21 Improving sensor reliability
2025-11-21 More sensor reliability changes
2025-11-21 Fixing IMU stability due to sensor reinitialisation
    [main.py, test3.py]
2025-11-21 fixed thread not stoping
    [test3.py]
2025-11-24 Updated documentation
    [CameraMountArm.stl, CameraMountBase.stl, SensorMount.stl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]
2025-11-25 Expand README with more schematic diagrams
    Added additional schematic diagrams and images for various components.
